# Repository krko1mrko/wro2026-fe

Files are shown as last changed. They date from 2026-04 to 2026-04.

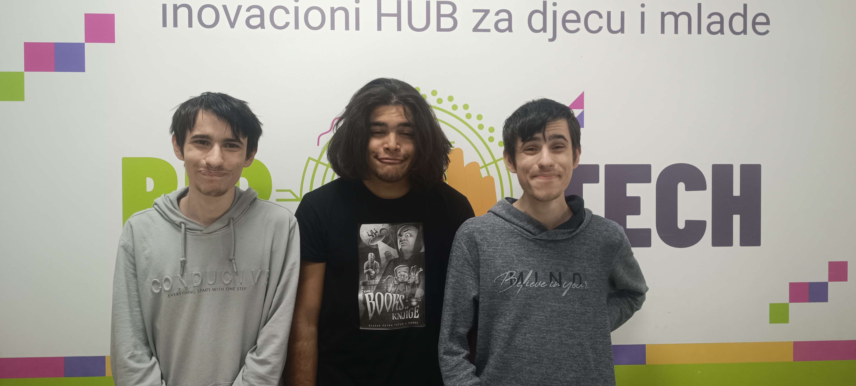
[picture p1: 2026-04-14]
t-photos/funny_image.jpg

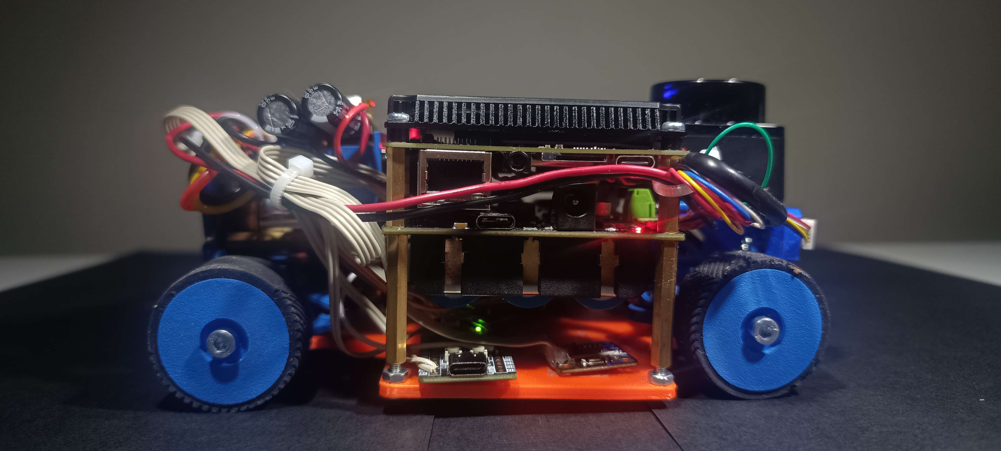
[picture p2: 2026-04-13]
v-photos/IMG_20260413_161818.jpg

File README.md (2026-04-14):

<br><h1 align=center> Team Ouroboros – WRO 2026 Future Engineers<br><br>

## Robot Overview

This repository contains the complete software system developed by Team Ouroboros for the WRO 2026 Future Engineers competition. The robot is a fully autonomous vehicle designed to complete both the Open Challenge and the Obstacle Challenge using a combination of advanced mechanical design and optimized software architecture.

The platform is based on a four-wheel drive and four-wheel steering configuration, allowing for improved maneuverability and traction. The software is designed to operate in real time, using multiple sensors and optimized algorithms for localization, perception, and decision-making.

---

## System Architecture

The system is divided into multiple modules, each responsible for a specific function. These modules interact to form a complete autonomous control pipeline.

### High-Level Data Flow

Sensor Data → Sensor Processing → Localization → Path Planning → Control → Actuation

---

## Software Modules

### 1. Sensor Interface Module

This module is responsible for acquiring and preprocessing data from all sensors used in the system.

Sensors include:
- LiDAR (STL-27L 360° DTOF) – environment mapping and obstacle detection  
- IMU (BNO055) – orientation and heading estimation  
- Camera (LattePanda 5MP UVC) – signal detection  
- Encoder (AS5600) – motor rotation and distance estimation  

The module ensures synchronized and structured data delivery to higher-level components.

---

### 2. Localization Module

The localization system determines the position and orientation of the robot within the map.

The main algorithm used is ICP (Iterative Closest Point), which aligns LiDAR scans with a pre-generated reference map. The odometry provides an initial estimate of the transformation to improve convergence speed.

To ensure real-time performance:
- A quad tree data structure is used for efficient spatial indexing  
- Approximate nearest neighbor search is implemented  
- OpenCL is used for GPU acceleration  

The output of this module is the robot’s pose (x, y, heading).

---

### 3. Path Planning Module

This module determines the optimal trajectory for the robot.

Two planning strategies are implemented:
- Open Challenge pathfinding  
- Obstacle avoidance pathfinding  

The planner uses the robot’s current position and environmental data to generate a path using Hybrid A* algorithm. It avoides obsticles while generating one of the shortest paths possible given the robot dynamics.

---

### 4. Obstacle Detection and Avoidance Module

This module processes LiDAR data and camera reading to detect dynamic obstacles and avoid them while following the signal rules.

Steps include:
- Detection of obstacles from point cloud data and camera readings
- Classification of detected objects
- Modification of trajectory to avoid collisions  

This module ensures safe navigation during the obstacle challenge.

---

### 5. Control Module

The control module converts planned trajectories into actuator commands. It uses a Stanley controller with a predictive element for mitigation of system response time.

Responsibilities include:
- Motor speed control
- Steering angle control
- Real-time corrections based on feedback  

This module communicates directly with the microcontroller for execution and operates on a separate thread for continious updating.

---

## Hardware and Software Integration

The software is tightly coupled with the robot’s electromechanical system. System parameters are updated in software to match the hardware.

### Main Components

- Main processor: Intel N150 (runs high-level algorithms)  
- Microcontroller: STM32 (handles real-time control)  
- Drive motor: BLDC motor with gearbox  
- Steering actuator: serial servo motor  

### Interaction

- The main processor processes sensor data and computes control commands  
- Commands are sent to the STM32 microcontroller  
- The STM32 controls motors and actuators  
- Feedback from sensors is continuously processed  

This separation ensures stable real-time performance.

---

## Build Instructions

### Dependencies

- Ubuntu operating system: (https://ubuntu.com/tutorials/install-ubuntu-desktop#1-overview)
- C++ compiler (g++) (https://gist.github.com/hugoledoux/2e91ed3efbfa8ca5da1ea27e522d2b34)
- OpenCL ICD:
    - OpenCL: https://github.com/KhronosGroup/OpenCL-Guide/blob/main/chapters/getting_started_linux.md
    - Driver: https://support.zivid.com/en/latest/camera/getting-started/software-installation/gpu/install-opencl-drivers-ubuntu.html
- OpenCV Library: (https://docs.opencv.org/3.4/d7/d9f/tutorial_linux_install.html)
- Arduino IDE  (https://support.arduino.cc/hc/en-us/articles/360019833020-Download-and-install-Arduino-IDE)
- STM32duino (https://github.com/stm32duino#welcome-to-the-stm32duino-open-source-community)
- SCServo Library (https://github.com/adityakamath/SCServo_Linux?tab=readme-ov-file#scservo_linux)
- Modified SimonK firmware for the ESC (Depending on your ESC choice, the firmware may vary) (https://github.com/sim-/tgy)

### Steps

1. Clone the repository and enter the directory:

```bash
git clone https://github.com/krko1mrko/wro2026-fe  
cd wro2026-fe/code
```

2. Build the project:

```bash
g++ *.cpp -fpermissive 'pkg-config --cflags --libs opencv4' -lOpenCL -O3 -o main
```

3. Ensure all dependencies are properly installed and linked.

---

### Microcontroller (STM32)

1. Connect the STM32 board via USB  
2. Open Arduino IDE or compatible environment  
3. Select the correct board and port  
4. Upload the firmware  

---

## Execution Loop

The system operates in a continuous loop:

1. Sensors acquire environmental data  
2. Data is processed and filtered  
3. Localization estimates robot pose  
4. Path planning determines next movement  
5. Control module generates commands  
6. STM32 executes motor and steering actions  

---

## Configuration

System parameters such as speed limits, control constants, and sensor calibration values
are defined within the source code and can be adjusted prior to compilation.

## Additional Notes

- The system minimizes external dependencies to improve portability  
- Performance is optimized through algorithm design and GPU acceleration  
- The modular structure allows easy debugging and future expansion  

---

## Repository Structure

/t-photos
/v-photos
/video
/CAD Files.zip
/wro2026-fe-ouroboros-docs
/README.md

---

## Conclusion

The presented system combines mechanical design and optimized software architecture to achieve reliable autonomous navigation. The modular design, efficient algorithms, and tight integration with hardware allow the robot to operate effectively within the constraints of the WRO 2026 Future Engineers competition.

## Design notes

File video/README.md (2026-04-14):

# Video Material

The following Youtube URL's are showing a 30 second robot video in both open and obstacle challenge.

- Open challenge: https://youtu.be/--TAmBv7YcM
- Obstacle challenge: https://youtu.be/LMDbXpmT5yE

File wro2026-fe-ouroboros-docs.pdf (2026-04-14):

# ROBOT DOCUMENTATION FOR WRO 2026 FUTURE ENGINEERS

## Team Ouroboros

## Authors: Blazo Barovic Lazar Milicevic Milos Milicevic

Introduction | 3
Abstract | 3
Mobility & Mechanical Design | 3
Chassis Design Choices | 3
Steering and Drive Mechanism Justification | 4
Torque/speed reasoning | 5
Mechanical Stability | 5
Power & Sensor Architecture | 5
Power System | 5
Processing Units | 6
Sensor System | 6
LiDAR | 6
IMU | 6
Camera | 6
Encoder | 6
Software Architecture & Obstacle Strategy | 7
Introduction | 7
Explanation of algorithms | 7
Localization Algorithm (ICP) | 8
Signal handling | 10
Signal Mapping | 10
Waypoint Generation | 10
Testing & Evaluation | 11
Mechanical Testing | 11
Localization Accuracy | 11
Algorithm Performance | 11
Revisions & Improvements | 11
Overall Revisions | 11
Tire Choice | 12
Design Process | 13
Conclusion | 16

## Introduction

In this documentation, we describe the thought process, implementation, and design challenges encountered during the WRO 2026 Future Engineers challenge. The focus of this document is not only to present the final system, but also to clearly explain the reasoning behind key design decisions and the trade-offs considered during development.

In addition, we present the working principles of the robot, including its mechanical design and the implementation of the algorithms used in the system.

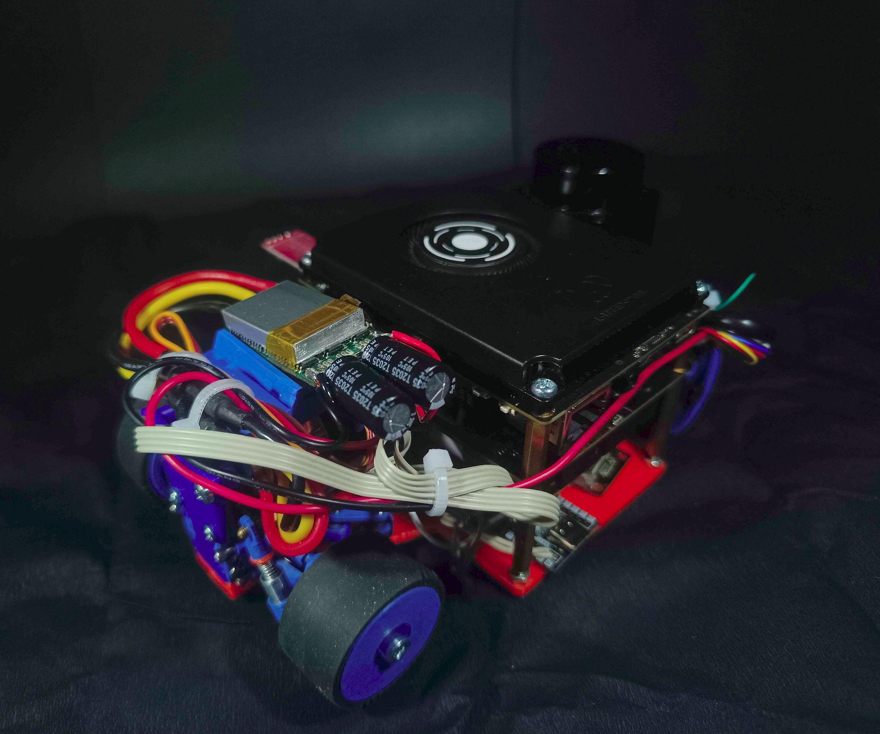
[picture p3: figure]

## Abstract

During the development of the robot for this year’s challenge, multiple design approaches were evaluated based on performance, complexity, and reliability. Due to these factors, the robot was designed as a four-wheel drive and four-wheel steering platform. This configuration was selected to improve traction, acceleration, and maneuverability, which are critical for navigating the competition environment.

The robot is equipped with passive suspension to ensure consistent contact of all four-wheels with the surface during operation. This improves stability and helps maintain reliable traction and sensor performance.

The robot utilizes multiple sensors to accurately determine its position and heading relative to the map. These sensors include a two-dimensional planar LiDAR sensor, a 9-DOF IMU, magnetic absolute position encoder and a 5-megapixel USB camera. Each sensor was selected for its specific advantages, and together they provide complementary data for robust perception and localization. The sensor data is processed and fused within the system.

For handling autonomous actions, the robot utilizes multiple algorithms corresponding to the challenges in this year’s competition. We use three different algorithms:

- Pathfinding algorithm for the open challenge
- Pathfinding algorithm for the obstacle avoidance challenge
- All-purpose localization algorithm

During development, we evaluated the accuracy and execution speed of individual subsystems, as well as the system as a whole, in order to ensure reliable real-time performance within hardware constraints.

## Mobility & Mechanical Design

Chassis Design Choices
During the development, the team has looked into multiple options for the chassis design based on the optimizations of the robot’s speed, acceleration and turning radius. The decision was made to keep the size of the robot as small as possible. This reduces our weight and increases our clearance from signals and walls during the locomotion of the robot. The robot is made using FDM (Fused Deposition Modeling) 3D printing technology. The plastic that is primarily used is PLA, but a select number of parts are made with ABS and TPU plastics. Other than plastic components, we use common mechanical parts such as bearings, screws, nuts, and heat inserts. We are also using off-the-shelf components such as: small form factor CVDs (Constant Velocity Drive) and open differentials, as well as metal gears. Some of the parts were manufactured out of aluminum using a lathe.
Robot mounting is primarily done by heat inserts and screws. Most of our screws mounting is done using M2 screws. Certain systems that are semi-decoupled from the robot base are attached with hinge joints and ball joints. These joints are made out of plastic using a 3D printer with a 0.25mm nozzle so that the feature size is as small as possible. This was a necessity because of the relatively small size of our robot (Figure 1.1).

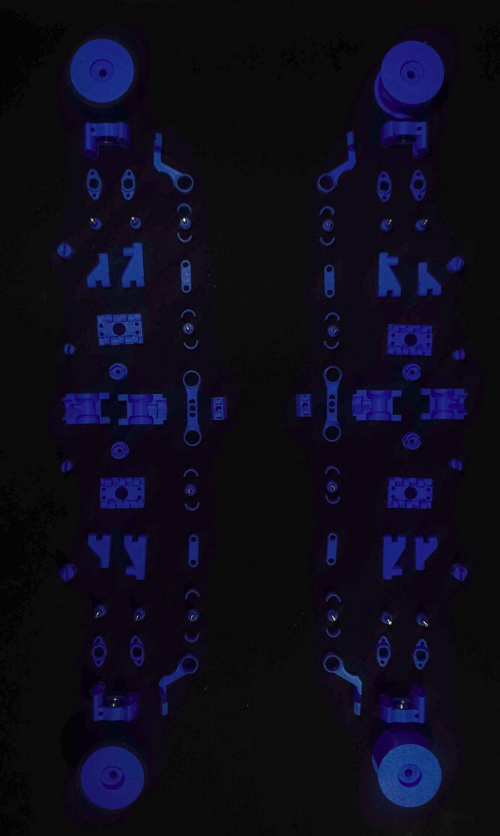
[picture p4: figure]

Steering and Drive Mechanism Justification
For the optimization of the robot’s speed and acceleration, we’ve decided to go with a four-wheel drive mechanism. This allows us to achieve higher acceleration by applying torque to all four-wheels, which increases our traction. Other factors that influence maximum speed and acceleration are choice of motor, gear ratio, tire diameter and material, excluding any aerodynamic effects.
Due to the additional challenge of parallel parking in the obstacle challenge, it was important to minimize turning radius. This also greatly benefits our ability to avoid signals and other collisions, significantly increasing our maneuverability. This is done by implementing a four-wheel steering mechanism. This considerably decreases our turning radius compared to two wheel steering. However, due to the limitation of using a single steering motor, we are incapable of dynamically adjusting the steering ratio of the front and back wheels. This forces us to optimize for either low speed or high speed maneuvers. Due to the nature of the challenge, this makes it so that optimizing for low speed maneuvers is more beneficial, therefore the steering ratio between the front and back axle is 1:1. The steering is inspired by Ackermann steering geometry.

The drive utilizes two differentials, one on the front axle and one on the rear axle, enabling four-wheel drive. Due to the expected symmetrical load distribution between the front and rear axles, a third (central) differential is not required.

Instead, both axles are directly coupled, which simplifies the drivetrain and reduces overall backlash in the system.

Torque/speed reasoning
Torque and speed heavily depend on motor choice, but some other factors are gear ratio and wheel diameter, as well as the mechanical transmission efficiency. The motor we chose to go with is a 2830 1000-KV motor. This provides us with high speed and low torque. Torque directly from the motor would be insufficient, thus a gearbox is used. The gearbox ratio is 10:1, whilst the final drive ratio is 2:1, giving us a total ratio of 20:1. The wheel diameter is 34mm. This provides us with a balance between our torque and speed, allowing quick acceleration with a high maximum speed. The motor is more powerful than the use case requires, therefore it’s limited to a max power and speed more in line with our needs.

Mechanical Stability
Some systems don’t require high stability, whilst for others it's crucial for it to be stable with low backlash and higher rigidity. Based on these factors, we have designed our system for the needs of our robot, thus, parts such as the steering knuckle, wishbones, hinge joints, the drive mechanism and the steering system are made as rigidly as possible within the size constraint, whereas parts such as electronics mounting, the backplate are made with limited strength to save space as these parts do not require it.

## Power & Sensor Architecture

The robot’s electrical and sensing architecture were designed to ensure reliable operation, efficient power distribution, and accurate data acquisition from all sensors.

Power System

The robot is powered using a 3S1P (3 Series, 1 Parallel) lithium-ion battery configuration. The battery was selected based on its energy density, discharge rate, and size constraints.

Power is distributed to different subsystems using Smart UPS Expansion Board for LattePanda IOTA (18650 Battery). Different voltage levels are required for various components:

- BLDC Motor: 12V, direct from battery
- Servo Motor: 12V, direct from battery

- Microcontroller STM32: 5V, from linear voltage regulator
- LiDAR: 5V, from USB
- BNO055 IMU: 3.3V, LattePanda IOTA breakout
- LattePanda 5MP UVC Camera: 5V, from breakout
- AS5600 Encoder: 3.3V, from STM32

Voltage regulation is handled using Smart UPS expansion board, ensuring stable operation and protecting sensitive electronics, as well as handling battery management functionality, such as overcharge protection, overdischarge protection and overcurrent protection.

Processing Units

The robot utilizes multiple processing units to handle different tasks:

- Main processor: Intel N150
- Microcontroller: STM32

The main processor is responsible for high-level tasks such as:

- Sensor fusion
- Localization
- Path planning
- Machine vision

The microcontroller is responsible for:

- Low-level motor control
- Servo control
- Real-time actuation

Sensor System

The robot uses a combination of sensors to achieve robust perception:

- LiDAR: Used for distance measurement and environment mapping
- IMU: Used for orientation and motion estimation
- Camera: Used for signal detection
- Encoder: Used to provide an approximate position estimate.

LiDAR

Model: STL-27L 360° DTOF LIDAR Sensor (UART, 25m)

- Range: 25m

The LiDAR provides point cloud data used for localization and obstacle detection, including environment mapping.

IMU

Model: BNO055

- Degrees of freedom: 9
- Data used: heading angle

The IMU provides high-frequency motion data used as an initial estimate in the localization algorithm.

Camera

Model: LattePanda 5MP UVC
Camera
- Resolution: 5 MP

The camera is used for signal detection.

Encoder

Model: AS5600

The AS5600 is a high-precision, 12-bit contactless magnetic rotary position sensor that provides absolute angle measurement over a 360-degree range. As we have attached it to the backside of the motor, where it measures rotation that can then be converted into distance traveled. The encoder was necessary because the accuracy of the robot was not ideal, therefore we needed to add a feedback loop.

### Actuators

For the actuation and movement of the robot, only two actuators are used. One being the steering servo, whilst the other one is the drive motor.
The steering servo is a serial servo supplied with 12V. The servo has three wires. Such that they are: 12V, GND and data. The servo serial communication is a half duplex UART (Universal Asynchronous Receive Transmit) connection running at a baud rate of 1M. Its commands are sent by the STM32 microcontroller.
The drive motor is a 1000KV 11 pole BLDC (Brushless DC) motor. This kind of motor relies on electronic communication which is handled by an ESC (Electronic Speed Controller). For the purposes of this vehicle it was needed for the speed controller to support bidirectional commutation. This is not a default setting in many affordable ESC’s used for such drone motors. For this reason, it was needed to flash a custom firmware that would enable such a feature. The firmware of choice was the popular SimonK. It’s tailor made for such cheap ATmega based ESC’s. The ESC is controlled by a PWM signal whose pulse width ranges from 1060-2060us. This PWM signal is generated by the STM32 microcontroller. It’s supplied with 12V, same as the servo.

## Software Architecture & Obstacle Strategy

Introduction
During the development of the robot software, it was the team’s goal to minimize external dependencies such as libraries, executables, or SDKs. For this reason the only dependencies used are OpenCL, OpenCV and Arduino libraries (SCServo, Servo).
The system is built on top of the open source operating system Ubuntu. Due to the hardware limitations in such a small form factor it was important to choose a highly performant programming language that allowed for low access and was compatible with the aforementioned libraries. The choice boiled down to C or C++, and C++ was chosen due to previous experience with the language.

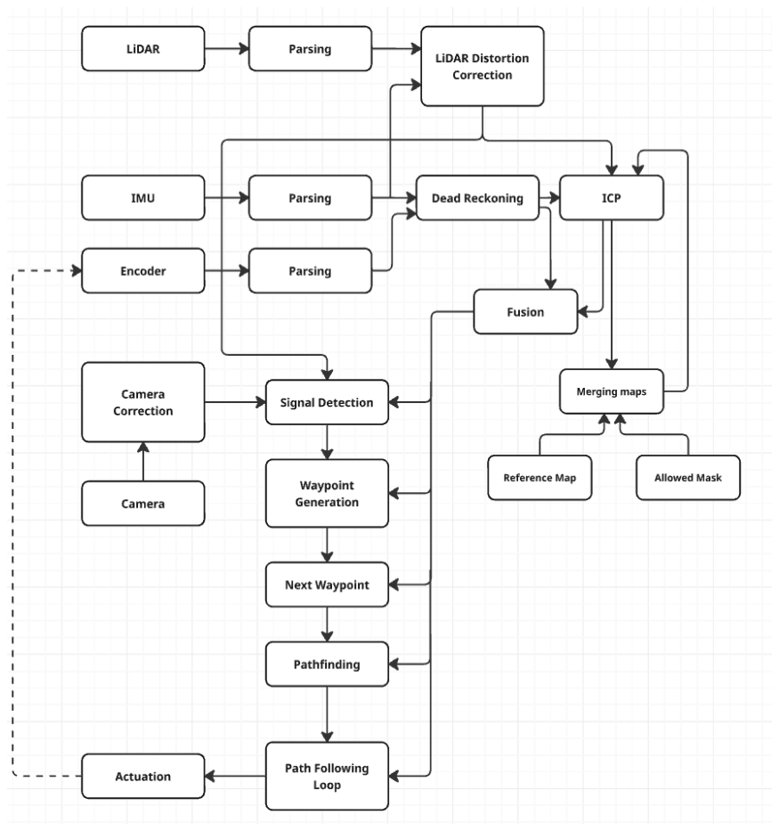
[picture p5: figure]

Explanation of algorithms

The main problem in robotics of this type boils down to 2 simple questions:
- Where is the robot?
- Where to go next?
To answer these questions many methods are used in the industry and research. The question of Where is the robot? is in essence a localization problem. Many robots on this scale use what is called dead reckoning using odometry. This is the process by which the robot's position is determined based on the previous robot position and a calculated or measured change in position from wheel encoders. But due to its iterative nature, any and all measurement errors will be added up, and they will tend to increase the error between our predicted position and real position. This is called drift. Previously on the WRO RoboMission 2025 our team developed such a system, but due to the previously mentioned drift as well as the significantly bigger track length of the WRO Future Engineers 2026 map that would amplify the total error further we decided to research other alternatives.
One method that is often mentioned in the literature is use of a local or global positioning system such as GPS or GNSS. But due to rule 11.6. - “A vehicle must be autonomous and finish the “missions” by itself. Any radio communication, remote control, and wired control systems are not allowed while the vehicle is running. Teams in violation of this rule will be disqualified.” that forbids external communication such methods are not useful for our use case. Another method is SLAM
(Simultaneous Localization and Mapping) using a combination of sensors. These sensors most often include LIDARs and IMUs. The SLAM system uses the LIDAR point cloud reading and matches it to a previously constructed map. This is most often done with the ICP (Iterative Closest Point) algorithm. The IMU provides an initial guess of the current transformation of the points. This guess is then used for the first iteration of ICP. This boosts convergence speeds and reduces possible errors, as long as the IMU readings are properly filtered. If the new readings are added to the map this will cause drift over time as small errors add up. This is often solved by a system often referred to as loop closure, but due to the algorithm’s complexity and relatively small and known environment for this challenge we decided it would be better if we performed ICP using a pre-generated map. This map would be appended with the dynamic elements of the challenge (signals or randomized walls).
Prebuilt solutions for such a SLAM system exist within software packages such as ROS 2, but due to the previously stated self-imposed limitations on the software dependencies, we decided to implement our own even if its performance is worse than existing solutions.

Localization Algorithm (ICP)

The ICP algorithm is used to align LiDAR scans with a pre-generated map. The algorithm iteratively minimizes the distance between corresponding points. For each point, in a LiDAR scan, it finds the closest point from the reference map forming a point pair. This is done with a nearest neighbor search algorithm. The exact implementation is described later. After forming the pairs, a least squares solution for the transform (including translation and rotation) is solved. This transform is then applied to the original scan and the process is repeated until the error converges or a maximum number of cycles is exceeded.

The nearest neighbor search (from now on NNS) is performed for all the points in the scan (around 2160) across all iterations (max. 100, average 20), in searches across a reference map containing approximately 10000 points. If a simple NNS algorithm that iterates for each point in the scan across the whole reference map to find the nearest point it quickly becomes computationally expensive. This approach would be unable to perform ICP in the 100ms between each LiDAR scan. A different implementation had to be used.

A different data structure for the reference map was the most effective solution. A spatially indexed data structure was chosen due to the relatively static nature of the reference map. Two options were considered:

1. K-D Tree
2. Quad tree

The main deciding factor was the simplicity of tree generation. Quad trees were easier to generate.

To further save on computation an approximate NNS algorithm was used. This involved only navigating down the quad tree once per point without backtracking. To accommodate this change, the reference map is rotated by 45° to decrease the chances of a line of points, aligning with the quad border.

This was still underperforming, so the next best optimization was multithreading. To take advantage of the onboard GPU for general purpose parallelized computation, an OpenCL kernel was used. As per recommendations in the OpenCL™ Developer Guide for Intel® Processor Graphics

1
. The biggest
performance increase comes from proper and efficient memory usage. To aid in this we decided to decrease the overall size of the quad tree data structure. Each quad is only 8 bytes big such that it contains an id (4 bytes) that describes the exact position of the quad and its size. The remaining 4 bytes are used for storing the children offset in the array and their number.
The whole data structure is stored in an array of quads with the first element being the quad tree root. In addition to this the position and size of the root elements are passed in as 3 constant values (x, y, width).
To further optimize the runtime of the OpenCL kernel we only pass in the scan points once, and on subsequent iterations of the ICP we only update the transform that is applied to these points. It might seem counterintuitive to perform the point transformation twice, once on the CPU and once on the GPU, but the memory bandwidth reduction greatly outweighs any computational increase.
After implementing all these optimizations the execution of ICP for a single scan goes from >1s for the naive NNS algorithm to below 50ms. The algorithm only uses one CPU thread and therefore allows for additional processes such as communication, control loops and related processes.

1https://www.intel.com/content/www/us/en/content-details/774834/opencl-developer-guide-for-intel-processor-graphics.ht ml (https://www.intel.com/content/www/us/en/content-details/774834/opencl-developer-guide-for-intel-processor-graphics.html)

### Creating & Updating Reference Map

The reference map used in the ICP starts with already predefined points such as the outer walls and in case of obstacle challenge the parking spot. This reference map is dynamic, points are added to it as the robot explores its environment. The points that are added are first put through a mask. This mask blocks out the addition of any points on the drive surface, excluding signal positions. We have a secondary check before adding any points. These points must temporally agree on their positions in multiple previous readings before being added.

### LiDAR Distortion Correction

To improve the accuracy and stability of the ICP algorithm, it is necessary to correct the LiDAR data in its uncorrected form. The points from LiDAR are distorted due to the robot rotating during the scan. We correct for this rotation with historical data from the IMU.

### Dead Reckoning

Dead Reckoning is the process in which we calculate the changing position and rotation based on inertial measurements of the robot. These measurements are heading from the IMU and motor encoder.

### Fusion

We are using the simplest sensor fusion implementation in case ICP fails to converge to a low cost value. We fall back on dead reckoning for position, until the ICP converges again.

### Pathfinding Algorithm

The pathfinding algorithm is an algorithm that takes in the environment map, current position, system parameters, target position information and returns us a valid path to our end goal. The algorithm takes into account both position and rotation of the robot as well as the target position. The environment map is a point cloud. It consists of points that represent the walls and signals as well as points that represent virtual walls constraining our movement to the desired path. A valid path is any path that the robot can execute without colliding with signals or walls and that gets it to the target position.
To achieve this we are using the Hybrid A* algorithm tailored to a Reeds-Shepp vehicle. This vehicle is described with a minimal turning radius. It can only perform one of six actions: move forwards and backwards, steer left or right during those motions as shown on the figure (Figure 1.2).

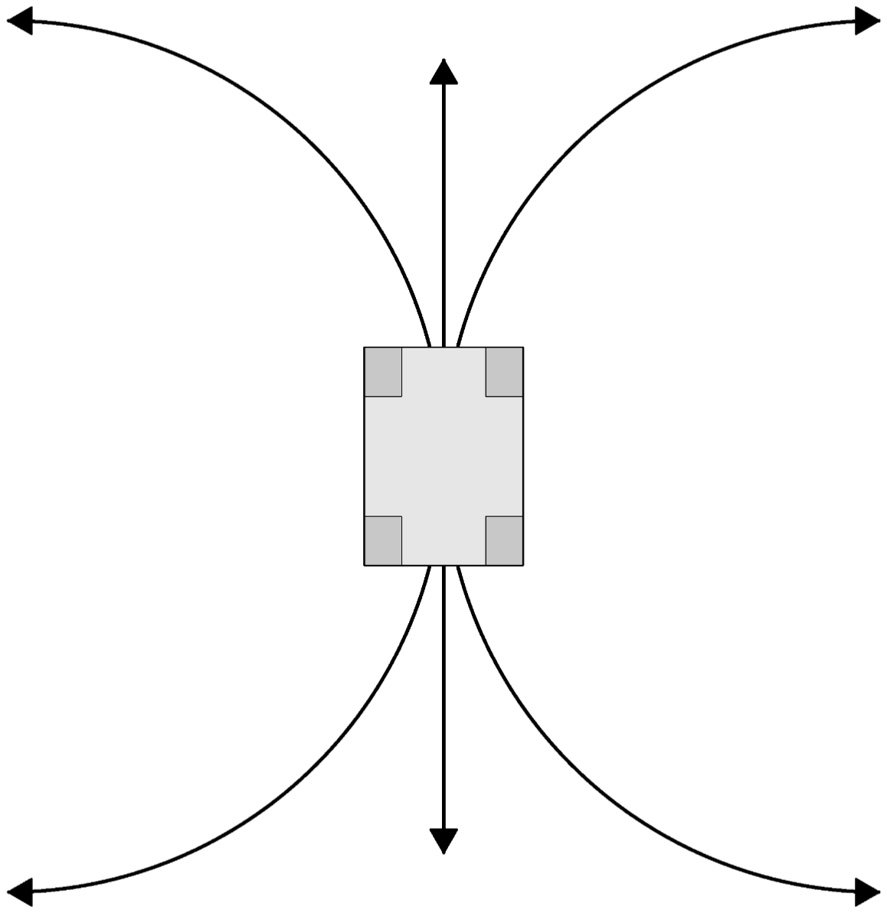
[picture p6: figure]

Figure 1.2.

Hybrid A* algorithm starts with a single node which is described by the vehicle's initial position and rotation. As this the only node, it is used for generation of six additional nodes. These new nodes correspond to the positions and rotations of the robot when traveling along each of the six possible movements for a distance equaling the step size. Each of these nodes check if the robot would collide with the environment in that position, this is a simple radial distance check. If it does collide, the node is deleted. For the remaining nodes, a cost is calculated. This cost is equal to the length of the shortest Reeds-Shepp path. These new nodes are inserted into an array of possible future positions. For the next iteration, the starting node is picked from this array, such that it is the element with the least cost. This process is repeated until one of three conditions are met:

1. There are no more possible nodes, in which case the
algorithm would return no
path.
2. If the computation time is exceeded, it returns no path.
3. If a valid Reeds-Shepp path is found from the last
explored node to the target position, such that the robot does not collide with the
environment whilst it follows that path. Then we return the Hybrid A* path with
appended Reeds-Shepp
path.

To determine if the Reeds-Shepp path produces a collision with the environment, we use an approach similar to ray marching where we iteratively go along the path for a minimum distance from the environment and on each spot we check if that minimum distance is less than a collision threshold. If for any of these points that condition is true, the path results in a collision.

### Starting Position

To find the initial position of the robot on the map, we used the previously described ICP algorithm and run a single iteration from each possible starting position and rotation and pick one with the lowest cost. Due to the symmetry of the map’s external walls, only twelve unique starting positions for the open challenge exist and only two for the obstacle challenge.

Signal handling

To perform signal handling we have to know three things: the drive direction of the vehicle during a round, the color of the signals and their positions. We have to know all three of these to be able to determine the positions of waypoints in global scope.

Signal Mapping

To determine the position and color of the signals, we use data from the camera, LiDAR and the position returned by the ICP algorithm. The first step is to calibrate the camera. This is done using OpenCV’s implementation of camera calibration. Next, we crop the image to the ROI (Region Of Interest) such that we exclude the ground and the area above the walls. We convert the RGB (Red, Green, Blue) to HSV (Hue, Saturation, Value). First we create the mask by checking all of the pixel values that match a value range of a color. In the mask, we find contours, iterate over them and delete any that are too small.

We redraw the image from the remaining contours.
We match the FOV of the camera to a region of the LiDAR’s FOV. Afterward, we find the average distance and angle from the LiDAR to a detected signal. This distance and angle are converted to global coordinates. We store these positions in an array. If four separate calculations agree that the signal is found close to a possible position, we will add a signal to that position. We separately check for green and red.

Waypoint Generation

Waypoints are used in our
pathfinding as target positions. These waypoints are crucial for our signal handling as they determine the factoring path chosen by the robot. When the robot is moving in a CCW direction and detects a green signal, it generates a waypoint that is located inwards a certain distance away from the signal and if it sees a red signal, it
generates a point outwards. This is reversed if the direction is reversed. The signals also generate a waypoint if the signal is located close to the corner segment, it also generates a waypoint that is located on the middle of its straight segment. The signal has the same direction as the drive direction. To aid in the single detection, we have four fixed waypoints one on each corner segment rotated towards the next straight segment. The robot follows these points in an order of the drive direction, i.e. CW or CCW.

### Path Following

If the path is followed strictly based on the Reeds-Shepp path, a lot of jitter can be observed. For this reason, it was needed to perform path smoothing and correct for any deviation from the path in real time. To do this, we implemented a Stanley controller. This controller looks at the closest point on the path and the current state of the robot to determine the needed steering of the vehicle to get back onto the path.
This implementation had significant oscillations due to the response delay of the system, mainly the limited rate of change of the steering servo. To fix this, we introduced a predictive element that predicts the future position and rotation of the robot and uses it to calculate the command for the servo. The prediction window is tuned such that by the time we reach the predicted point in time, servo has moved to the position
commanded to it at the time of making the prediction.
In addition to this, if we are nearing the end of the planned path, we command the drive motor to decelerate.

## Testing & Evaluation

During development, the system was tested to evaluate performance, accuracy, and reliability.

Mechanical Testing

- Minimum turning radius: 330mm
- Maximum speed: 0.7

m
s
- Speed used: 0.5

m
s
- Acceleration: 0.25

m
s

2

Algorithm Performance

- Average computation time for the ICP algorithm: 5-90ms
- Average computation time for the pathfinding algorithm: 0-20ms

## Revisions & Improvements

Overall Revisions

During development, we had two major revisions: the first was purely conceptual design made fully parametric and fully adjustable for the sake of validation out the suspension and steering geometry.

This design was large, bulky and had fundamental flaws for the design. The good part about the initial design was its parametric nature. That allowed us to quickly adapt it after the initial time invested into making it parametric. This revision was primarily used before we committed to any choice of hardware, such as bearings, tires, CVD’s, differentials, gearbox, motor, etc.

The next major change was an overall reduction of size of all parts. Before any big changes, we aimed to evaluate the hardware we could use. We had a vast selection of parts to choose from on the bearing front, as well as on the drive train or drive base parts such as: CVD’s, shafts and differentials.

Tire Choice

But our biggest problem at the time was the material for tires. We were unable to source two part silicone, thus we needed to find a more readily available solution. After evaluation our choices, we had two options:

1. Caulk silicone
2. Silicone bike grips

From our previous experiences, we knew that we could manufacture tires out of caulk silicone. These tires would have pretty good performance, but we still wanted to evaluate the other options we did not try in the past that, after some research, we thought the second option of silicone grips could have better or equal performance than caulk silicone.

However, it depends on the material used and the geometry of the grips. We decided our best course of action was to check in local bicycle shops their selections of handle grips. We found what we were searching for, and evaluated that it had slightly better traction and was significantly sturdier than a solution made with caulk silicone.

Because of the fixed size of the inner diameter of the silicone grips, that was the approximate size we had to go with for our rims. This size could be slightly bigger as the silicone is stretchable. At the end, we decided to have a 26mm outer diameter of our rims whilst the grips had an inner diameter of 21mm. This ensures that the grips will not slip on the rim even with no patterns on the surface of the rim. The inside diameter of the rim is 24.5mm. From this choice, the scale of our steering knuckle and all the connected mechanisms were derived.

In this revision, the scale of the entire mechanism was reduced by a factor of two. Most of the hardware, i.e. bearings and joint sizes were finalised and a basic untuned steering geometry was implemented. The third and final revision mostly dealt with tuning: steering, gear meshing, suspension mechanisms, as well as tolerances for printed 3D-printed parts.

The first implemented steering was simplified Ackermann steering geometry. Whilst the subsequent revisions dealt with adapting such geometry to work with suspension and within our size constraints.

The following figures show our steering geometry in different development stages.

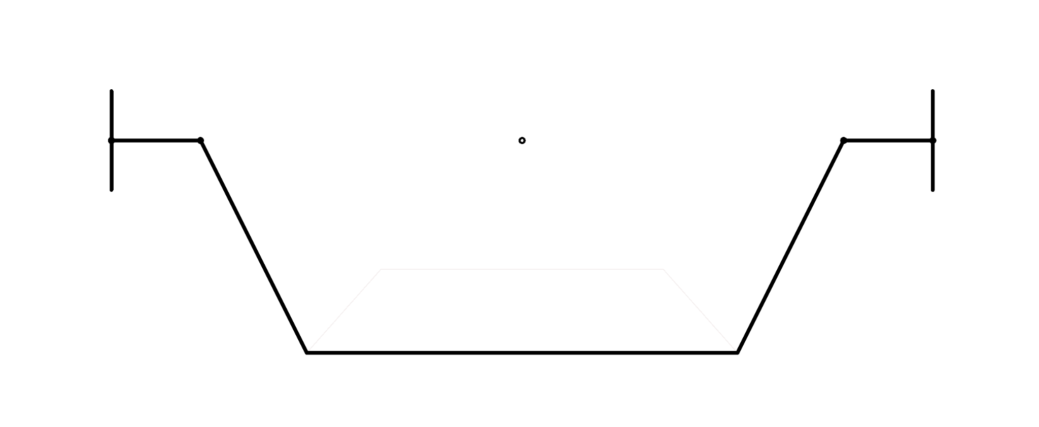
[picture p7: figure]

Figure 1.

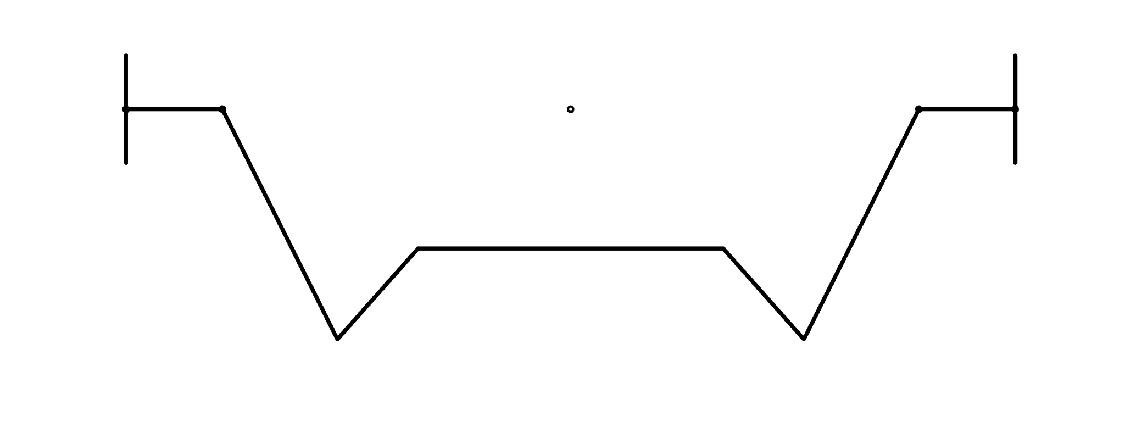
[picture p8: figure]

Figure 2.

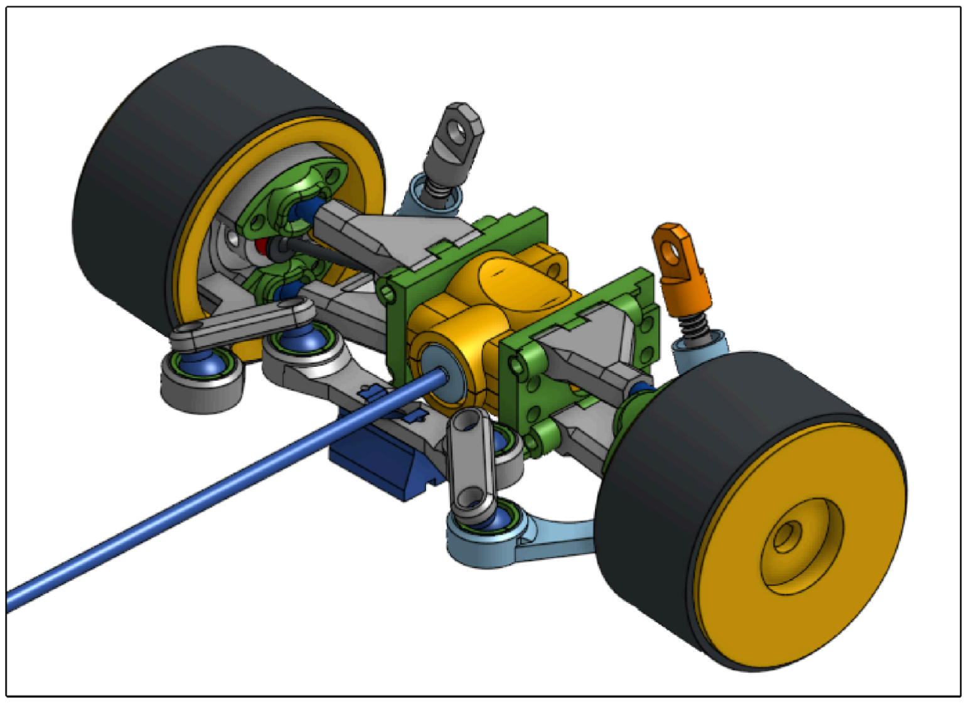
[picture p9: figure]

Figure 3.

Design Process

First version of the steering knuckle. This version was simplistic and meant as a proof of concept. It contained minimal features and did not satisfy our criteria, it was difficult to implement and hard to alter the CAD design (Figure 4.).

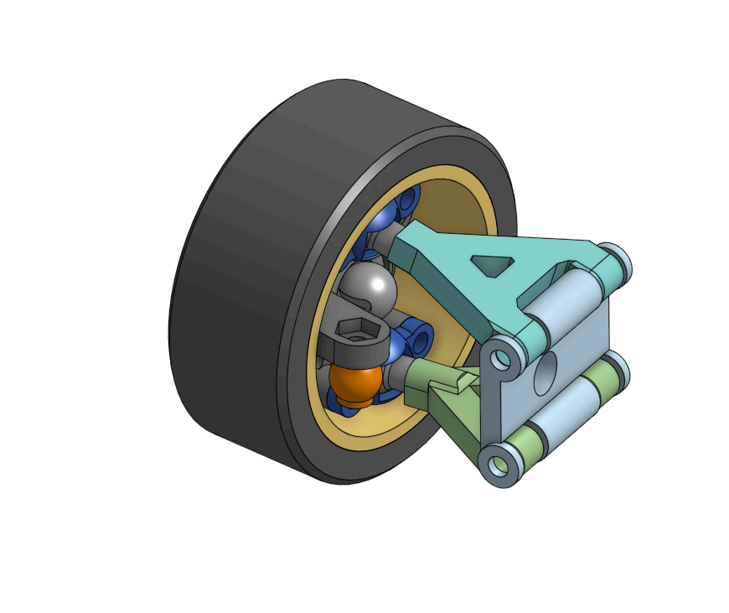
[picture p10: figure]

Figure 4.

Rework of the steering knuckle. Included caster angle and KPI in the initial base design. Did a fully parametric design for fast revisions. Finalized the design of the ball joints, connecting the steering knuckle to the wishbones (Figure 5.).

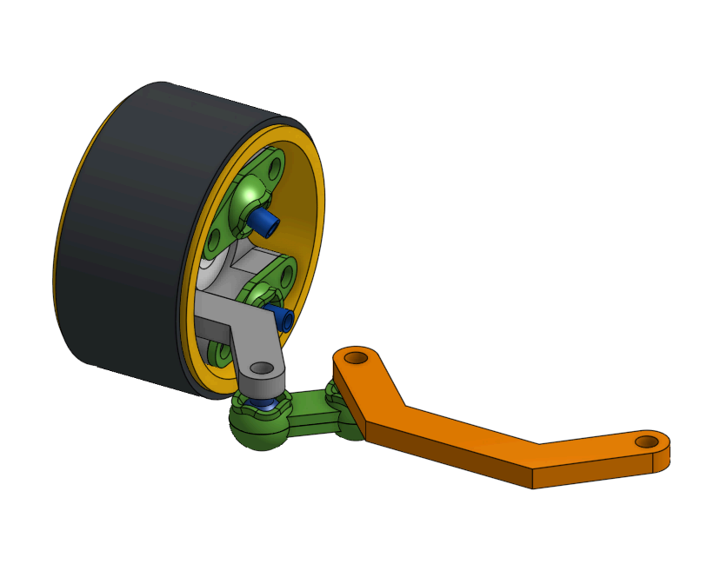
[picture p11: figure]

Figure 5.

Changed designed parameters, finalized size and determined tolerances used in printing of joints. Determined the usefulness of dry lubricants such as graphite, which did improve the performance of these joints (Figure 6.).

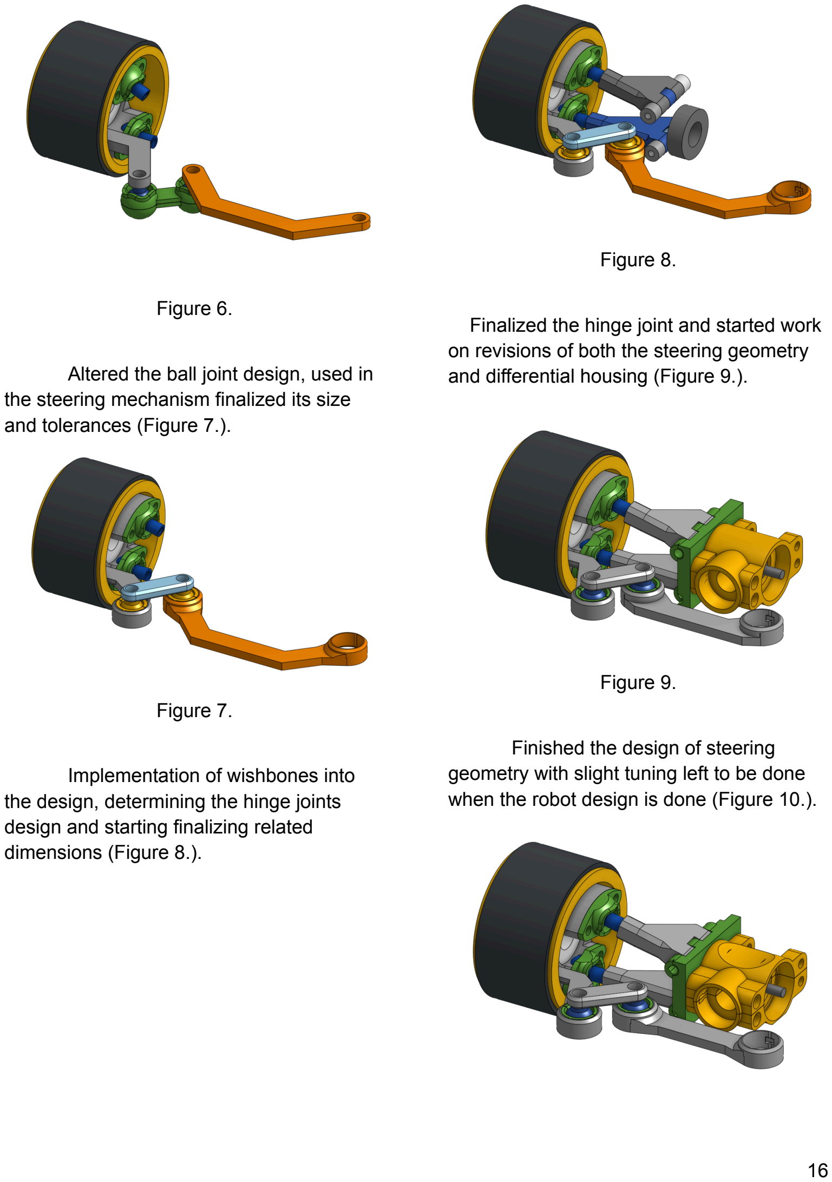
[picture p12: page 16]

Figure 6.

Altered the ball joint design, used in the steering mechanism finalized its size and tolerances (Figure 7.).

Figure 7.

Implementation of wishbones into the design, determining the hinge joints design and starting finalizing related dimensions (Figure 8.).

Figure 8.

Finalized the hinge joint and started work on revisions of both the steering geometry and differential housing (Figure 9.).

Figure 9.

Finished the design of steering geometry with slight tuning left to be done when the robot design is done (Figure 10.).

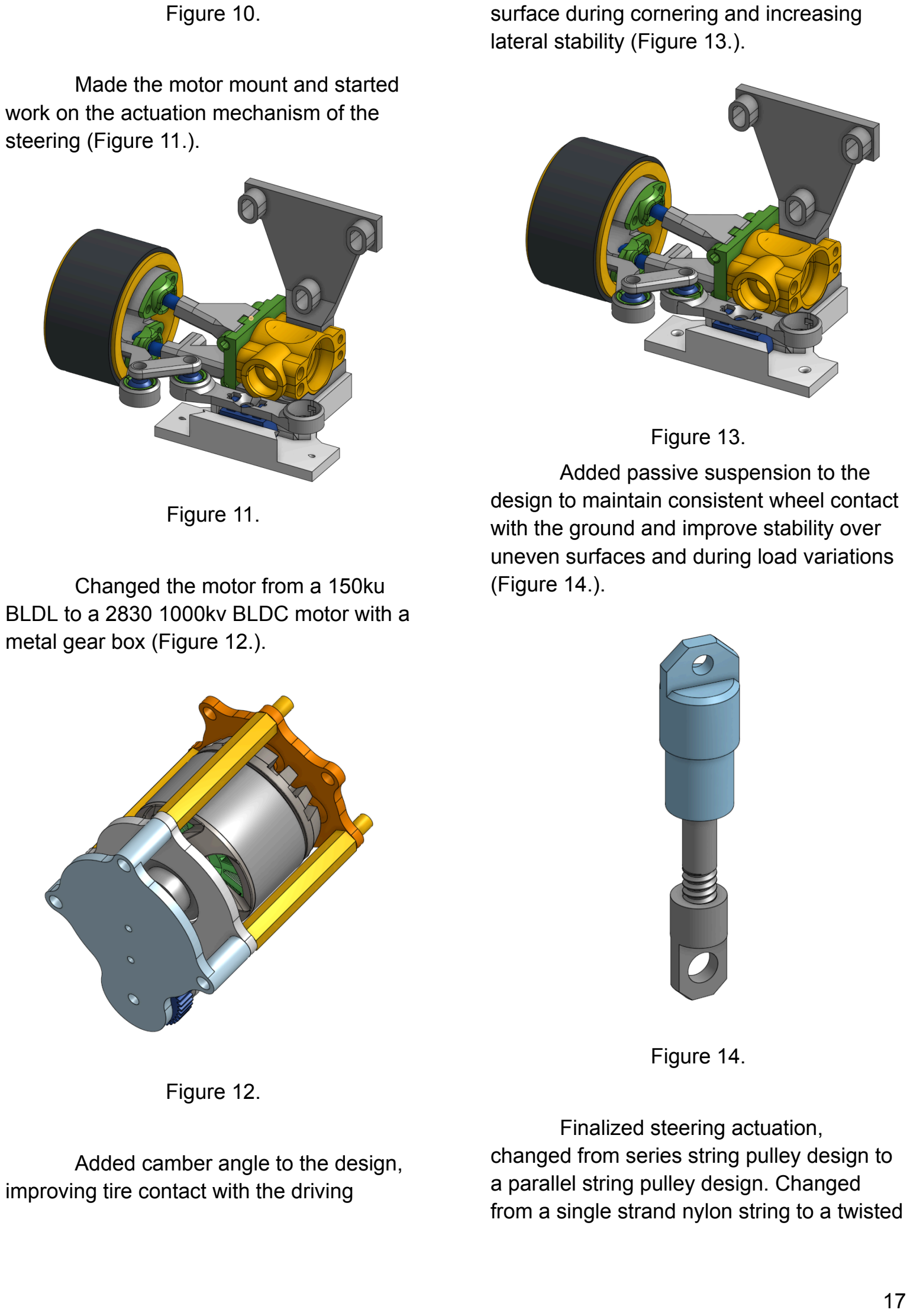
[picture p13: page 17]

Figure 10.

Made the motor mount and started work on the actuation mechanism of the steering (Figure 11.).

Figure 11.

Changed the motor from a 150ku BLDL to a 2830 1000kv BLDC motor with a metal gear box (Figure 12.).

Figure 12.

Added camber angle to the design, improving tire contact with the driving surface during cornering and increasing lateral stability (Figure 13.).

Figure 13.
Added passive suspension to the design to maintain consistent wheel contact with the ground and improve stability over uneven surfaces and during load variations (Figure 14.).

Figure 14.

Finalized steering actuation, changed from series string pulley design to a parallel string pulley design. Changed from a single strand nylon string to a twisted fishing line made to not stretch or deform (Figure 15. & 16.).

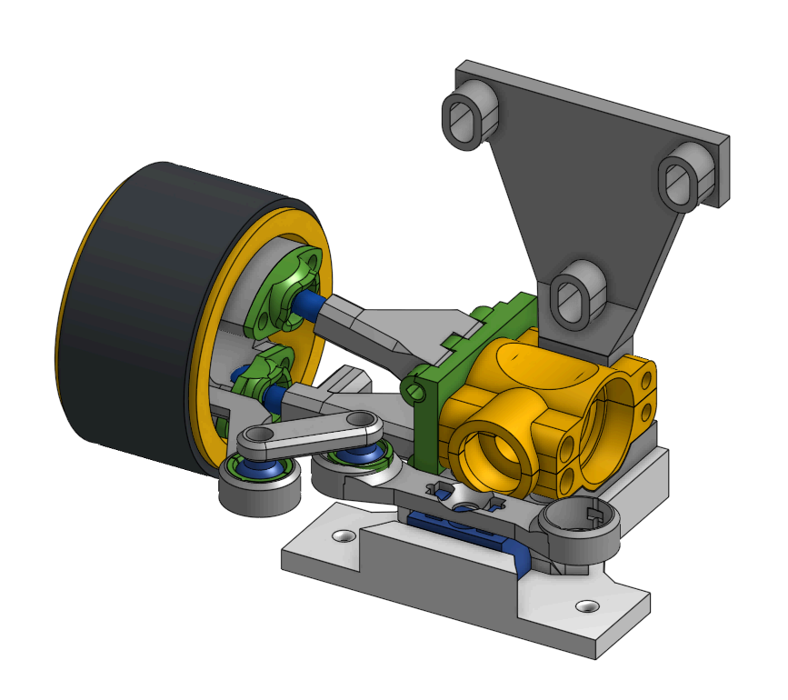
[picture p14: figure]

Figure 15.

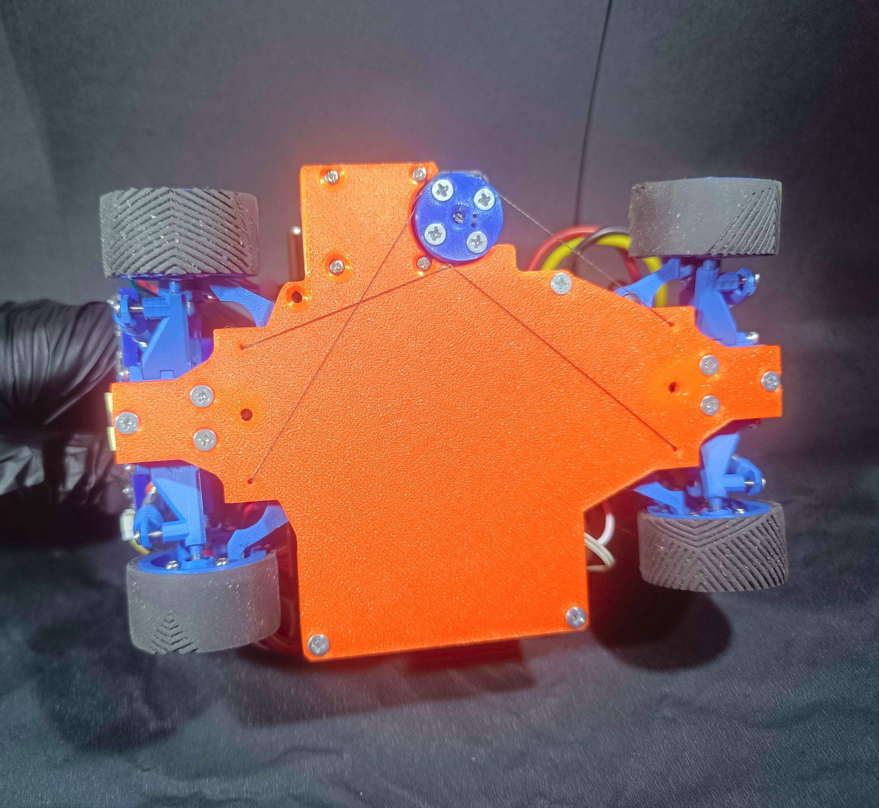
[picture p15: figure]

Figure 16.

The back board on which all the components are connected, changed tolerances and string channel sizes as well as added alignment holes used when tightening the steering actuation (Figure 17.).

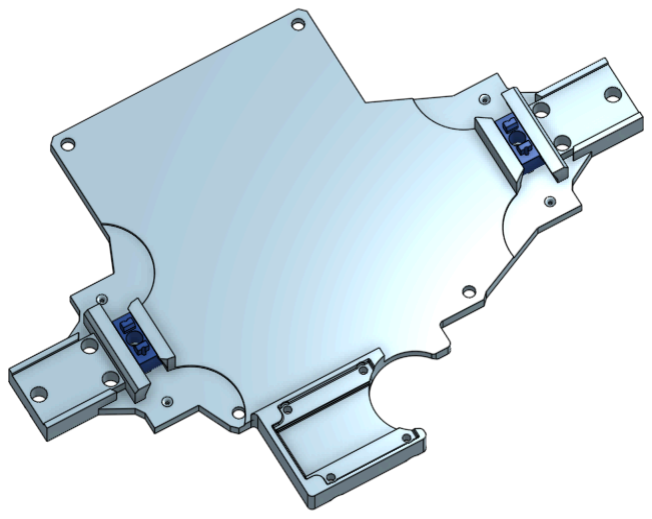
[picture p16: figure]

Figure 17.

## Conclusion

The developed robot represents a carefully balanced integration of mechanical design, sensor architecture, and software systems, with a strong emphasis on reliability, efficiency, and real-time performance.

Throughout the development process, each subsystem was iteratively refined and evaluated to ensure that it meets the constraints and challenges defined by the WRO 2026 Future Engineers competition.

The combination of a four-wheel drive and four-wheel steering platform provides high maneuverability and precise control, which is essential for navigating complex environments. The use of a LiDAR-based localization system, supported by IMU data and optimized through a custom implementation of the ICP algorithm, enables accurate and stable position estimation without reliance on external infrastructure.

In addition, the integration of path planning and obstacle handling algorithms allows the robot to adapt to both static and dynamic elements of the environment, ensuring safe and efficient navigation. Special attention was given to computational performance, resulting in a system capable of operating within strict real-time constraints.

Although further improvements can be made in certain areas, the current implementation demonstrates a robust and optimized solution. Overall, the system reflects a comprehensive engineering approach, combining theoretical understanding with practical design decisions to successfully address the requirements of the competition.

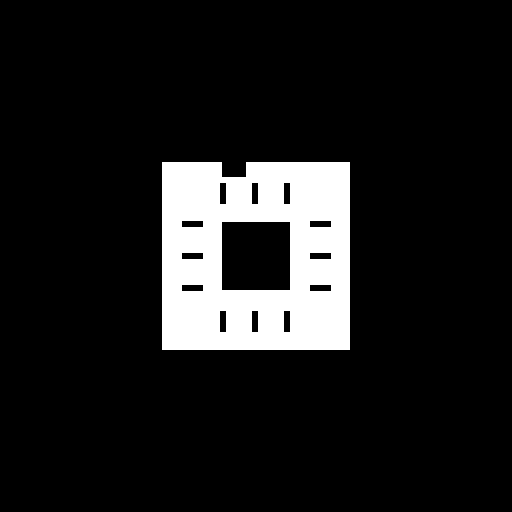
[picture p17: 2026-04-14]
code/obsticle_challenge_mask.bmp

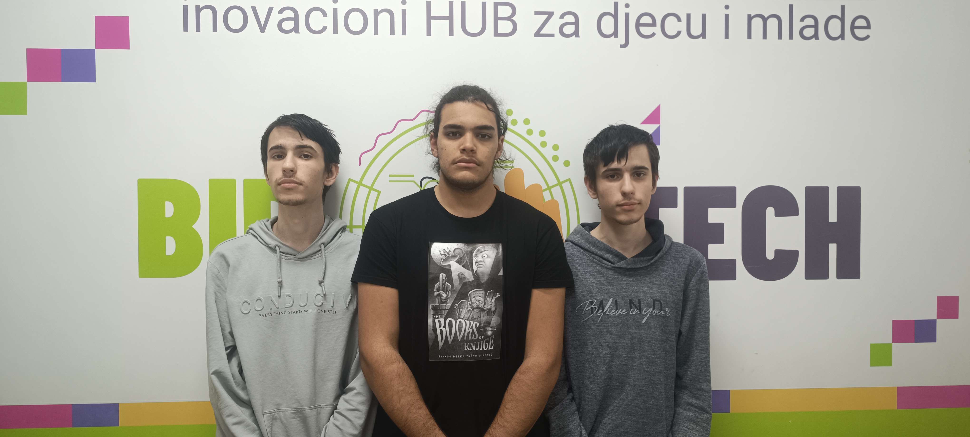
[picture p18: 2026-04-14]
t-photos/serious_image.jpg

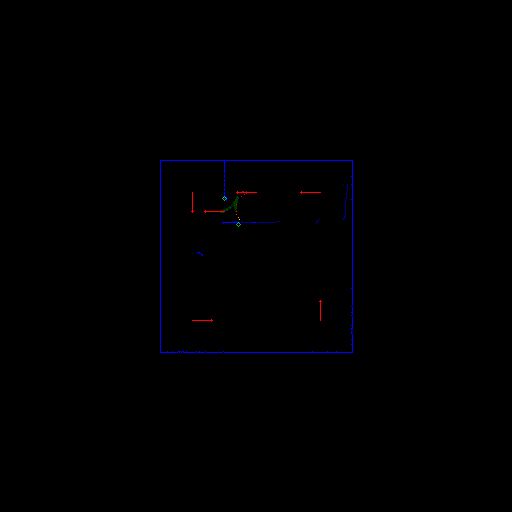
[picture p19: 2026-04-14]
code/raw_map.bmp

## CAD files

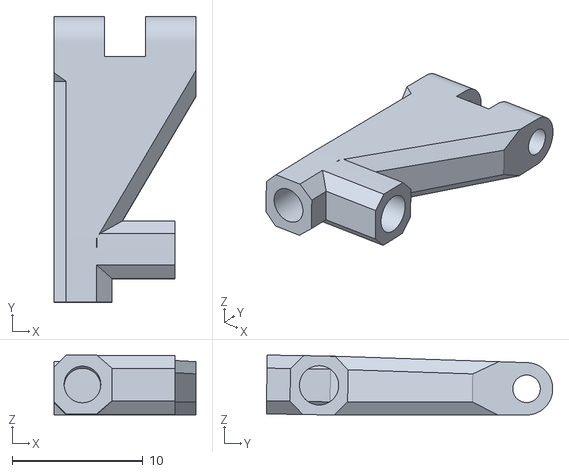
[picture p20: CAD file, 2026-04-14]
CAD Files/Confidence - Right Wishbone Bottom.stl
10.8 x 21.9 x 4.58

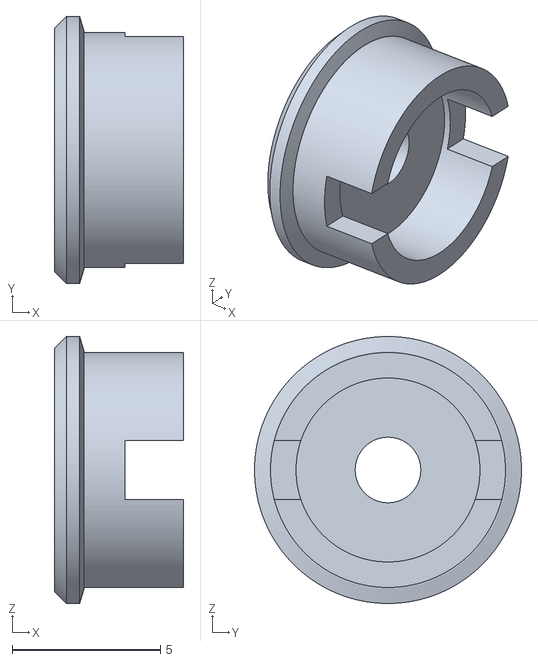
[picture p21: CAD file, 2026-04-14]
CAD Files/Confidence - Diff Bearing sleeve.stl
4.35 x 9.00 x 9.00

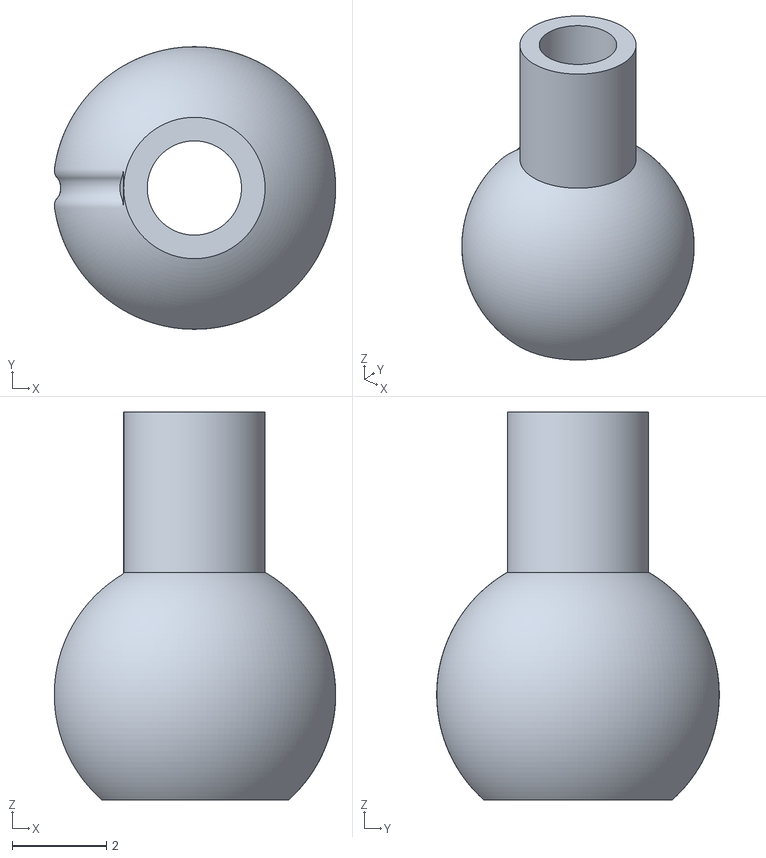
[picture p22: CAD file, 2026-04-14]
CAD Files/Confidence - Ball Joint.stl
5.97 x 6.00 x 8.24

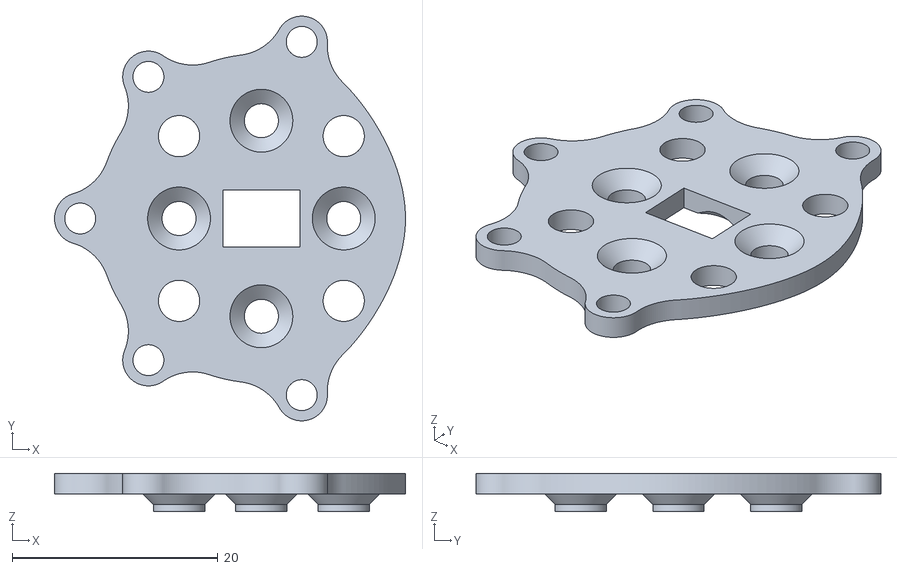
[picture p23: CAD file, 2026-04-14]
CAD Files/Confidence - Gearbox Motor Back Mount.stl
34.1 x 39.3 x 3.70

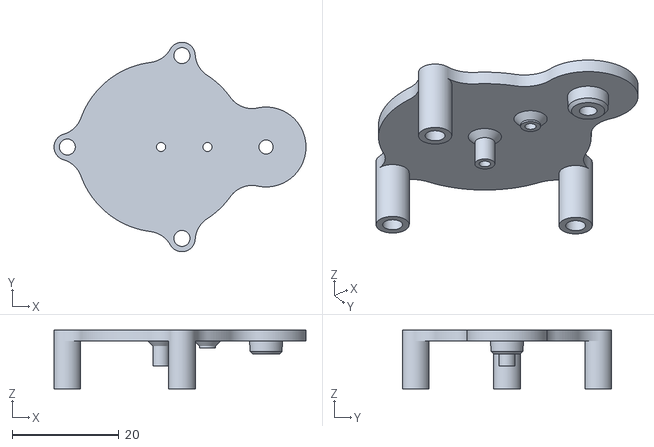
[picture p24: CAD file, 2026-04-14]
CAD Files/Confidence - Gearbox Motor Mount Front.stl
47.3 x 39.3 x 11.0

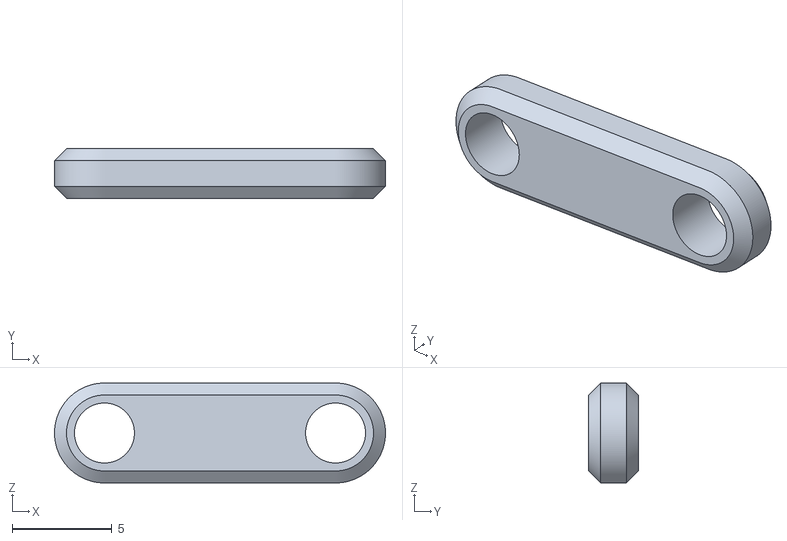
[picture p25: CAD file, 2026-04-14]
CAD Files/Confidence - Arm.stl
16.6 x 2.50 x 5.00

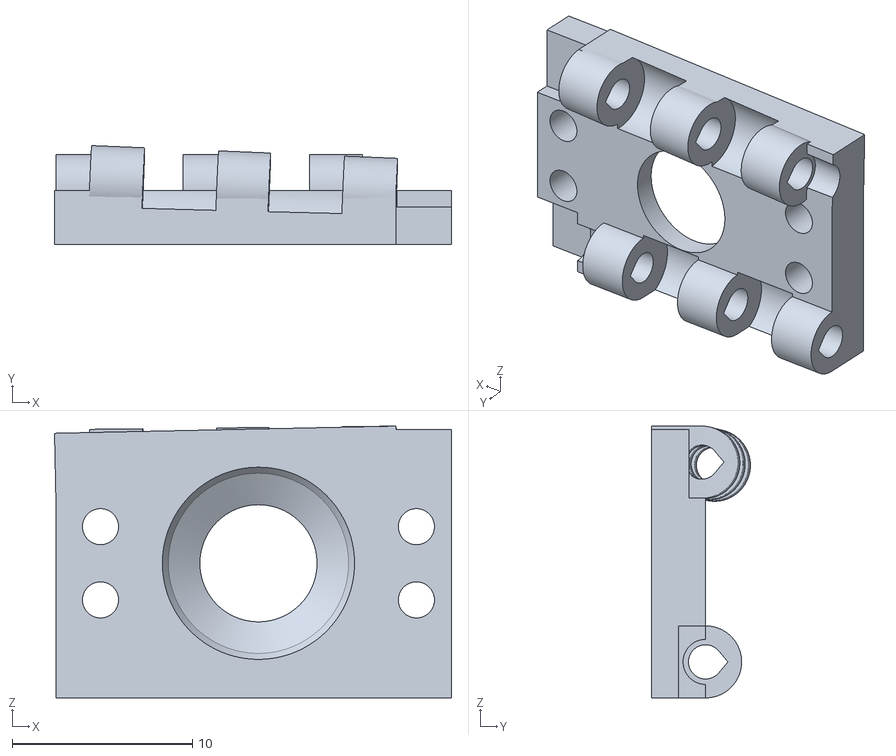
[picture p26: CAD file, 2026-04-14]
CAD Files/Confidence - Right Hinge Joint Back.stl
22.0 x 5.49 x 15.1

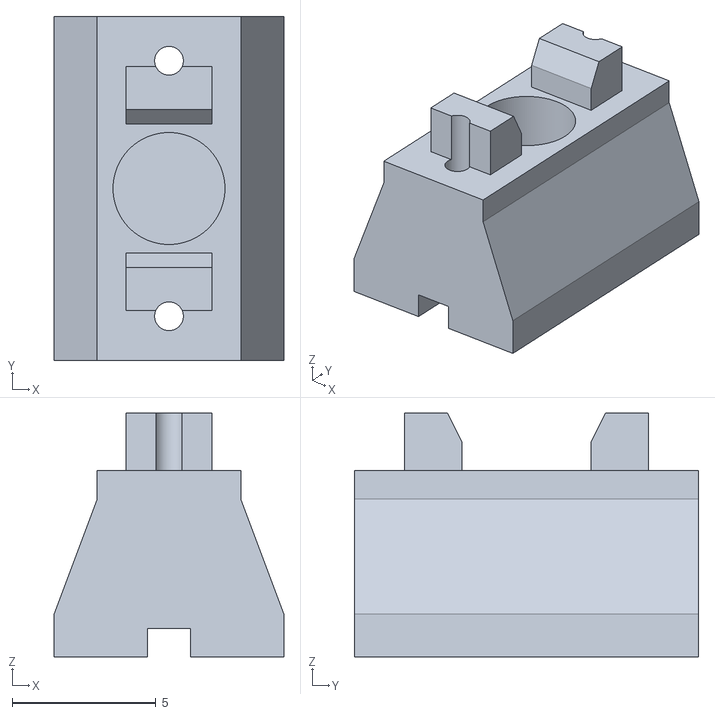
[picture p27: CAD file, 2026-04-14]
CAD Files/Confidence - String Mounting.stl
8.00 x 12.0 x 8.50

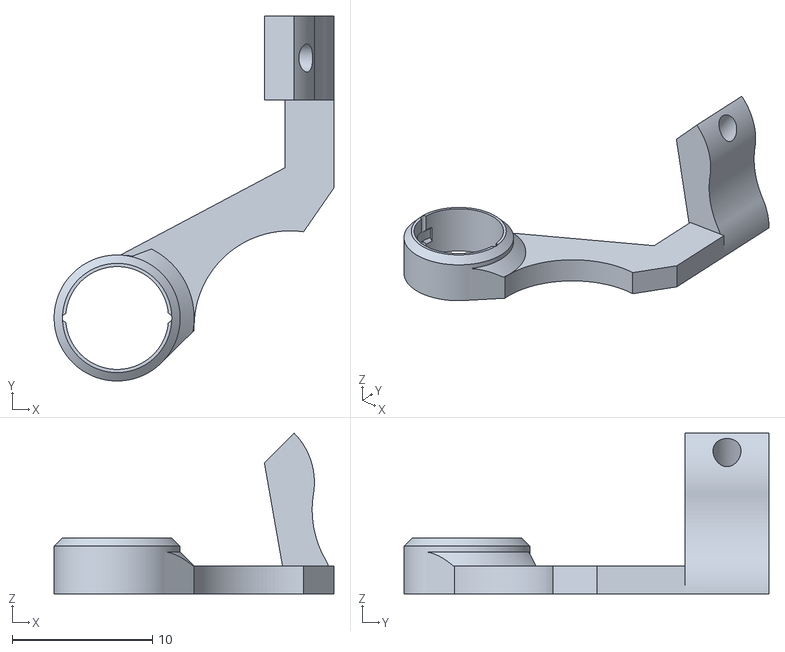
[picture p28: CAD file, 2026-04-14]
CAD Files/Confidence - Left Arm.stl
20.0 x 26.1 x 11.5

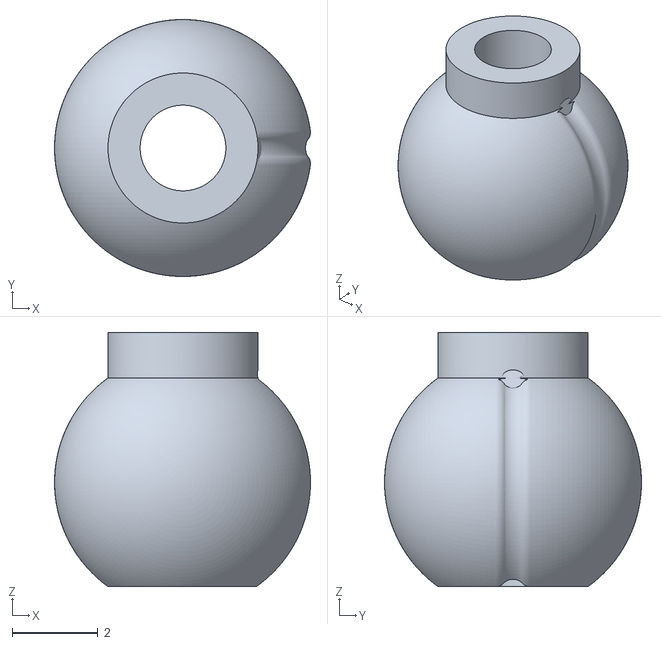
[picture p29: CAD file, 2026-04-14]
CAD Files/Confidence - Ball Joint A.stl
5.98 x 6.00 x 5.94

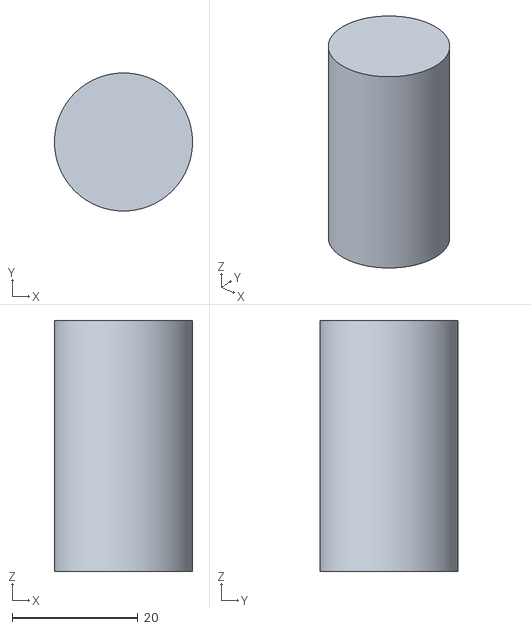
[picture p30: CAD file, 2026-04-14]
CAD Files/Confidence - Tire Cutting Tool.stl
22.0 x 22.0 x 40.0

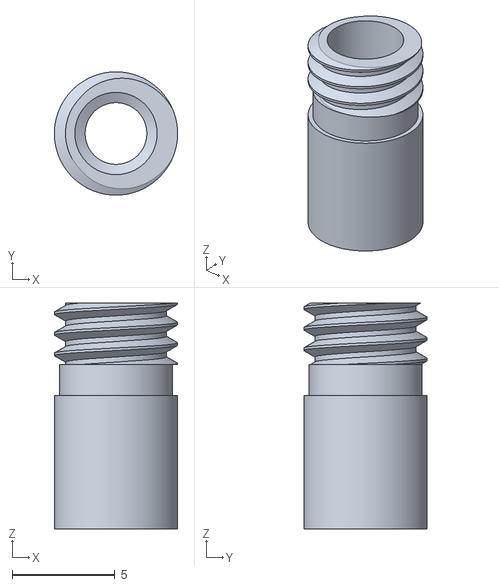
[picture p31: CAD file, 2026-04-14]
CAD Files/Confidence - Suspention Casing.stl
6.00 x 6.00 x 11.0

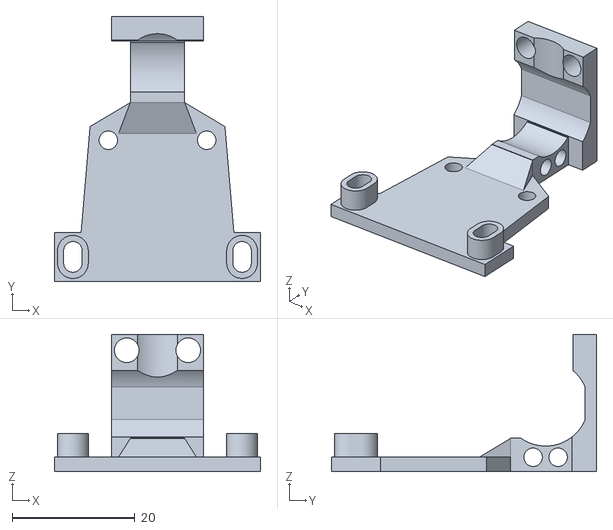
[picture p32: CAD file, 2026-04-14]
CAD Files/Confidence - Motor Mounting.stl
33.5 x 43.1 x 22.3

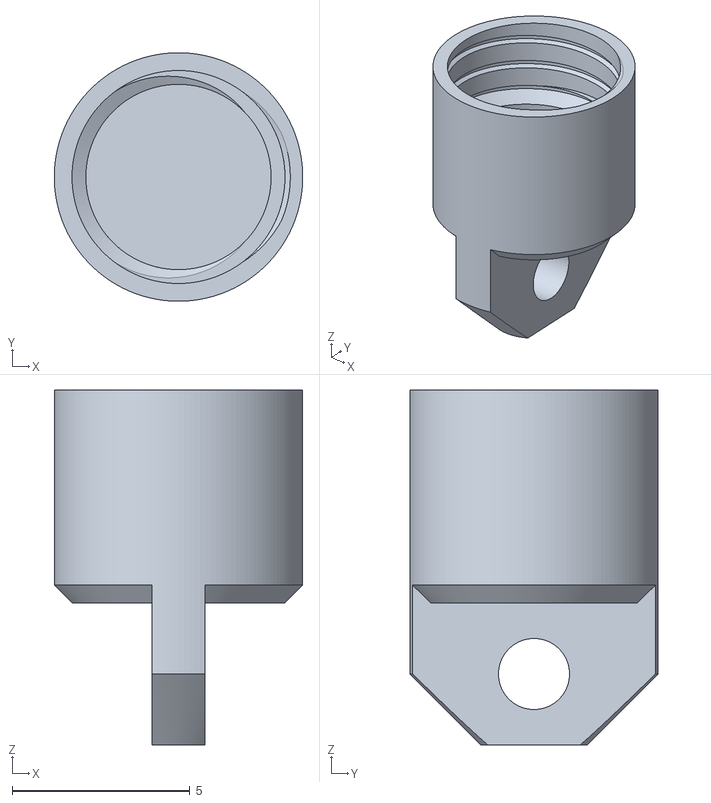
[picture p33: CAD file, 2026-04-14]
CAD Files/Confidence - Suspention Bottom.stl
7.00 x 7.00 x 10.0

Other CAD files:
CAD Files/Confidence - Left Wishbone Bottom.stl
CAD Files/Confidence - Right Hinge Joint.stl
CAD Files/Confidence - Suspention Top.stl
CAD Files/Confidence - Lidar Mounting.stl
CAD Files/Confidence - Ball Joint B.stl
CAD Files/Confidence - Differential Casing A.stl
CAD Files/Confidence - Differential Casing B.stl
CAD Files/Confidence - Flexible Cupling B.stl
CAD Files/Confidence - Flexsible Cupling A.stl
CAD Files/Confidence - Gearbox Motor Mount Middle.stl
CAD Files/Confidence - Left Arm Back.stl
CAD Files/Confidence - Left Body.stl
CAD Files/Confidence - Left Bottom Ball Joint Socket.stl
CAD Files/Confidence - Left Hinge Joint Back.stl
CAD Files/Confidence - Left Hinge Joint.stl
CAD Files/Confidence - Left Upper Ball Joint Socket.stl
CAD Files/Confidence - Left Wishbone Upper.stl
CAD Files/Confidence - Middle Arm.stl
CAD Files/Confidence - Right Arm Back.stl
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

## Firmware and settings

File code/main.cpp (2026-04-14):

#include "Config.h"
#include <iostream>
#include "stl27_driver.h"
#include "bno055_driver.h"
#include "icp.h"
#include "vison.h"
#include "drive.h"
#include "thread"
#include "pid.h"
#include "lookup.h"
#include "pathfinding.h"
#include "consts.h"
#include "signal.h"
#include "utils.h"


cv::Mat img = cv::Mat(512, 512, CV_8UC3, cv::Scalar(0,0,0,0));
void Display(std::vector<Point> reference){
    img -= cv::Scalar(150, 50, 1);
    int zoom = 64;
    for (Point& p: reference) {
        
        img.at<uchar>(std::clamp((int)(p.y * zoom + 256), 0, 511), std::clamp((int)(p.x * zoom + 256), 0, 511), 0) = 255;
        //cv::circle(img, cv::Point((int)(p.x * 256 + 256), (int)(p.y * 256 + 256)), 1, cv::Scalar(255,255,255));
        //img(cv::Rect(std::clamp((int)(p.x * zoom + 256), 0, 511), std::clamp((int)(p.y * zoom + 256), 0, 511), 1, 1)) = cv::Scalar(255, 0, 0);
        //img.at<uchar>(std::clamp((int)(p.x * zoom + 256), 0, 511), std::clamp((int)(p.y * zoom + 256), 0, 511)) = 255;
    }
    cv::imshow("cmb",img);
    return;
}

    std::vector<Point> reference;
    std::vector<std::vector<Point>> old_scans;
    double position_start[3] = {0, 0, 0};
    float target[3] = {};


    float last_click[2];
    float click_index = 0;
    bool has_target = false;
    void mouse_callback(int  event, int  x, int  y, int  flag, void *param)
    {
        if (event == cv::EVENT_LBUTTONDOWN ) {
            float x_cord = ((float) x - 256) / 64;
            float y_cord = ((float) y - 256) / 64;
            
            //HybridAStar pathfinder = HybridAStar(0.3, 0.2, Node(x_cord, y_cord, position_start[2] + PI / 2), Node(position_start[0], position_start[1], position_start[2] + PI / 2 ));
            //pathfinder.SetEnviorment(&reference);
            //std::vector<Node> pth;
            //int num = pathfinder.CalculatePath(&pth);
            
            if (click_index++ == 1) {
                target[0] = last_click[0];
                target[1] = last_click[1];
                target[2] = -atan2(last_click[1] - y_cord, -last_click[0] + x_cord);
                click_index = 0;
                cv::arrowedLine(img, cv::Point(last_click[0] * 64 + 256, last_click[1] * 64 + 256), cv::Point(last_click[0] * 64 + 256 + cos(target[2]) * 100, last_click[1] * 64 + 256 + sin(target[2]) * 100) , cv::Scalar(0, 0, 255));
                has_target = true;
            }
            last_click[0] = x_cord;
            last_click[1] = y_cord;

        }
    }

    void AddLine(std::vector<Point>* in, float x0, float y0, float x1, float y1, float density) {
        float len = sqrt((x0 - x1) * (x0 - x1) + (y0 - y1) * (y0 - y1));
        len *= density;

        for (int i = 0; i < len; i++) {
            float k = (float)i/len;
            in->push_back(Point(x0 * k + x1 * ( 1 - k), y0 * k + y1 * ( 1 - k)));
        }
    }

    


    int main() {
        std::cout << "Mode: Obsticle challenge\n";
        std::cout << "Initilizing robot sensors\n";

        Stl27_lidar lidar("/dev/ttyUSB0");
        lidar.FirstReading(1000); //Wait for first reading
        
        Bno055 imu("/dev/ttyS0");
        
        PointPair::quad_tree_opencl->CompileKernel();

        DriveBase car("/dev/ttyACM0");
        car.BindImu(&imu);


        while (true) {
            bool condition = true;
            for (int i = 0; i < 2; i++) {
                condition &= car.IsButtonPressed();
                std::this_thread::sleep_for(std::chrono::milliseconds(100));
            }
            if (condition) {
                break;
            }
        }

        car.SetLedPWM(5);
        std::this_thread::sleep_for(std::chrono::milliseconds(100));
        

        #ifdef OBSTACLE_CHALLENGE
        Vision vis;
        vis.AddLidar(&lidar);
        vis.AddImu(&imu);
        #endif

        

        cv::Mat allowed_point_mask = cv::imread("obsticle_challenge_mask.bmp", cv::ImreadModes::IMREAD_GRAYSCALE);

        #ifdef DEBUG_DISPLAY
        cv::namedWindow("cmb");
        cv::setMouseCallback("cmb", mouse_callback);
        cv::namedWindow("cmb");
        cv::moveWindow("cmb", 600, 0);
        #endif

        std::this_thread::sleep_for(std::chrono::milliseconds(100));
        
        
        AddLine(&reference, -1.5, -1.5, 1.5, -1.5, 100);
        AddLine(&reference, 1.5, -1.5, 1.5, 1.5, 100);
        AddLine(&reference, 1.5, 1.5, -1.5, 1.5, 100);
        AddLine(&reference, -1.5, 1.5, -1.5, -1.5, 100);
        #ifdef OBSTACLE_CHALLENGE
        AddLine(&reference, -0.5, -1.5, -0.5, -1.3, 100);
        AddLine(&reference, -0.25, -1.5, -0.25, -1.3, 100);
        #endif

        std::this_thread::sleep_for(std::chrono::seconds(1));
        
        std::vector<Point> compare_start;
        lidar.GetBilateralFiltered(&compare_start, imu, true);
        #ifdef OBSTACLE_CHALLENGE
        std::vector<std::vector<float>> possible_positions = {
            {-0.25, -1.0, PI/2},
            {-0.25, -1.0, -PI/2},
        };
        #endif
        #ifdef OPEN_CHALLAGE 
        std::vector<std::vector<float>> possible_positions = {
            {-0.25, -0.7, -PI/2},
            {-0.25, -1.0, -PI/2},
            {-0.25, -1.3, -PI/2},
            {+0.25, -0.7, -PI/2},
            {+0.25, -1.0, -PI/2},
            {+0.25, -1.3, -PI/2},
            {-0.25, -0.7, +PI/2},
            {-0.25, -1.0, +PI/2},
            {-0.25, -1.3, +PI/2},
            {+0.25, -0.7, +PI/2},
            {+0.25, -1.0, +PI/2},
            {+0.25, -1.3, +PI/2},
        };
        #endif
        
        std::vector<float> best_position = BestPosition(possible_positions, reference, compare_start);

        #ifdef DO_PARK_END
            Waypoint::final_waypoint = Waypoint(-0.3725, -1.4, best_position[2] + PI/2, true);
        #else
            Waypoint::final_waypoint = Waypoint(best_position[0], best_position[1], best_position[2] + PI/2, true);
        #endif
        
        Signal::Direction direction = Signal::Direction::CW;
        
        position_start[0] = best_position[0];
        position_start[1] = best_position[1];
        position_start[2] = best_position[2];

        if (best_position[2] > 0) {    
            direction = Signal::Direction::CCW;
        }
        
        #ifdef OBSTACLE_CHALLENGE
        Waypoint(1, -1, PI / 2 + (direction == Signal::Direction::CW ? 0 : PI/2), 500);
        Waypoint(1, 1, PI + (direction == Signal::Direction::CW ? 0 : PI/2), 500);
        Waypoint(-1, -1, (direction == Signal::Direction::CW ? 0 : PI/2), 500);
        Waypoint(-1, 1, 3 * PI / 2 + (direction == Signal::Direction::CW ? 0 : PI/2), 500);
        #endif
        #ifdef OPEN_CHALLENGE
        Waypoint(1.2, -1.2, PI / 2 + (direction == Signal::Direction::CW ? -PI/4 : 3*PI/4));
        Waypoint(1.2, 1.2, PI + (direction == Signal::Direction::CW ? -PI/4 : 3*PI/4));
        Waypoint(-1.2, -1.2, (direction == Signal::Direction::CW ? -PI/4 : 3*PI/4));
        Waypoint(-1.2, 1.2, 3 * PI / 2 + (direction == Signal::Direction::CW ? -PI/4 : 3*PI/4));
        #endif

        
        float imu_offset = imu.GetHeading() - position_start[2];
        car.SetHeadingOffset(imu_offset);
        #ifdef DEBUG_INPUT
        bool auto_skip = false;
        #else 
        bool auto_skip = true;
        #endif
        
        auto last_pathfind = std::chrono::high_resolution_clock::now();
        auto waypoint_time = std::chrono::high_resolution_clock::now();
        auto imu_recalibration_timeout = std::chrono::high_resolution_clock::now();
        int waypoint_timeout = 0; 

        while(true) {

            std::vector<Point> compare;
            lidar.GetBilateralFiltered(&compare, imu, true);
            
            auto start_time = std::chrono::high_resolution_clock::now();
            
            position_start[2] = AngleMod(position_start[2]);
            Point delta_drive = car.GetDelta(-position_start[2] - PI/2);
            position_start[0] += delta_drive.x;
            position_start[1] -= delta_drive.y;
            position_start[2] = imu.GetHeading() - imu_offset;
            for (Point &p :compare) {
                p.Transform(position_start[0], position_start[1], position_start[2]);
            }


            ICP icp;
            float dx = 0;
            float dy = 0;
            float da = 0;
            double cost;
            int iterations = icp.Compute(compare, reference, dx, dy, da, cost, false);
            
            #ifdef DEBUG_DISPLAY
            Display(compare);
            #endif

            if (!isnanf(dx) && !isnanf(dy) && !isnanf(da) && abs(dx) < 0.25 && abs(dy) < 0.25 && abs(da) < 0.32 && cost < 0.5) {
                Point total = Point(0, 0);
                total.Transform(position_start[0], position_start[1], position_start[2]);
                total.Transform(dx, dy, da);
                
                position_start[0] = total.x;
                position_start[1] = total.y;
                position_start[2] = da + position_start[2];
                icp.MergeMaps(reference, old_scans, 4, allowed_point_mask);
                old_scans.push_back(compare);
            
                if (cost < 0.025 && std::chrono::duration_cast<std::chrono::milliseconds>(std::chrono::high_resolution_clock::now() - imu_recalibration_timeout).count() < 1000) {
                    position_start[2] = AngleMod(position_start[2]);
                    imu_offset = imu.GetHeading() - position_start[2];
                    car.SetHeadingOffset(imu_offset);
                }
            }

            #ifdef OBSTACLE_CHALLENGE
            std::vector<Signal> signals = vis.DisplayFrame();
            for (Signal& s : signals) {
                s.Transform(position_start[0], position_start[1], position_start[2]);
                if (abs(s.x) < 1.4 && abs(s.y) < 1.4) {
                    cv::circle(img, cv::Point(s.x * 64 + 256, s.y * 64 + 256), 0.03535 * 64, s.color == Signal::Color::RED ? cv::Scalar(0, 0, 255, 255) : cv::Scalar(0, 255, 0, 255));
                }
                
            }
            Signal::MergeSignals(signals, direction);
            #endif
            
            std::vector<Point> reference_copy = reference;
            #ifdef OBSTACLE_CHALLENGE
            for (Signal& s : Signal::total_signals) {
                if (abs(s.x) < 1.4 && abs(s.y) < 1.4) {
                    cv::circle(img, cv::Point(s.x * 64 + 256, s.y * 64 + 256), 0.03535 * 64, s.color == Signal::Color::RED ? cv::Scalar(0, 0, 255, 255) : cv::Scalar(0, 255, 0, 255));
                }
                s.AddVirtualWall(&reference_copy);
                s.AddWaypoint();
            }
            #endif

            for (Waypoint& w : Waypoint::waypoints) {
                cv::arrowedLine(img, cv::Point(w.x * 64 + 256, w.y * 64 + 256), cv::Point(w.x * 64 + 256 + cos(w.a) * 20, w.y * 64 + 256 + sin(w.a) * 20) , cv::Scalar(0, 0, 255));
            }
            
            #ifdef DEBUG_DISPLAY
            Display(reference_copy);
            #endif

            Node car_pos = Node(position_start[0] + sin(position_start[2]) * 0.065, position_start[1] - cos(position_start[2]) * 0.065, position_start[2] + PI/2);
            car.UpdatePosition(car_pos.x, car_pos.y, car_pos.a);

            if (has_target && std::chrono::duration_cast<std::chrono::milliseconds>(std::chrono::high_resolution_clock::now() - last_pathfind).count() > 100) {
                last_pathfind = std::chrono::high_resolution_clock::now();

                HybridAStar pathfinder = HybridAStar(0.35, 0.08, Node(target[0], target[1], target[2]), car_pos);
                pathfinder.SetEnviorment(&reference_copy);
                std::vector<Node::NodeReedSheps> pth;
                Node::NodeReedSheps current_drive_node = car.GetCurrentNode();
                int num = pathfinder.CalculatePath(&pth, current_drive_node);
            
                if (num < 0) {
                    has_target = false;
                }
                else {
                car_pos.pathfinder = &pathfinder;
                std::vector<Node> vis_path = Subdevide(pth, &car_pos);

                for (int i = 0; i < vis_path.size(); i++) {
                    cv::circle(img, cv::Point((int)(vis_path[i].x * 64 + 256), (int)(vis_path[i].y * 64 + 256)), 1, cv::Scalar(0,255,0));
                }

                car.DrivePath(pth, 5000, car_pos.x, car_pos.y, car_pos.a);
                }
            }
            
            if (sqrt((target[0] - car_pos.x) * (target[0] - car_pos.x) + (target[1] - car_pos.y) * (target[1] - car_pos.y)) < 0.2 && abs(AngleMod(target[2] - car_pos.a)) < 0.2  && has_target) {
                has_target = false;
                waypoint_time = std::chrono::high_resolution_clock::now();
                std::vector<Node::NodeReedSheps> pth_temp;
                car.DrivePath(pth_temp, 10, car_pos.x, car_pos.y, car_pos.a);
            }

            img(cv::Rect(std::clamp((int)(position_start[0] * 64 + 256), 0, 511), std::clamp((int)(position_start[1] * 64 + 256), 0, 511), 1, 1)) = cv::Scalar(0, 255, 255);
            
            auto end = std::chrono::high_resolution_clock::now();
            std::cout << "loop took: " << std::chrono::duration_cast<std::chrono::milliseconds>(end - start_time).count() << "ms \t";
            std::cout << "dr delta: " << delta_drive.x << ", " << delta_drive.y << ", " << car.EncoderAngle() << "\t";
            std::cout << std::fixed << std::setprecision(3) << position_start[0] << ", " << position_start[1] << ", " << position_start[2]  << ", imu:" << imu.GetHeading() - imu_offset << ", " << cost * 1000 << ", " << iterations << "\n";
            
            #ifdef DEBUG_INPUT
            int id = cv::waitKey(1);

            if (id == 97) {
                std::vector<Node::NodeReedSheps> pth_temp;
                car.DrivePath(pth_temp, 10, car_pos.x, car_pos.y, car_pos.a);
                car.SendCommand(0,0);
                std::this_thread::sleep_for(std::chrono::milliseconds(1000));
                car.SetLedPWM(50);
                return 0;
            }
            else if (id == 83) {
                auto_skip = !auto_skip;
            }
            else if (id == 115) {
                cv::imwrite("raw_map.bmp", img);
            }
            #endif

            if (auto_skip && !has_target && std::chrono::duration_cast<std::chrono::milliseconds>(std::chrono::high_resolution_clock::now() - waypoint_time).count() > waypoint_timeout) {
                std::cout << "\n NEXT WAYPOINT CALLED \n\n";

                if (Waypoint::reached_final) {
                    std::vector<Node::NodeReedSheps> pth_temp;
                    car.DrivePath(pth_temp, 10, car_pos.x, car_pos.y, car_pos.a);
                    car.SendCommand(0,0);
                    std::this_thread::sleep_for(std::chrono::milliseconds(1000));
                    car.SetLedPWM(50);
                    return 0;
                }
                
                Waypoint w = Waypoint::GetNextWeypoint(position_start[0], position_start[1], (bool)direction);
                target[0] = w.x;
                target[1] = w.y;
                target[2] = w.a;
                has_target = true;
                waypoint_timeout = w.wait;          
            }

        }
    }

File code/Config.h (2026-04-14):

#pragma once



#define OBSTACLE_CHALLENGE
#define DO_PARK_END

//#define OPEN_CHALLENGE


#define NUMBER_OF_TURNS 3

#define DEBUG_DISPLAY
#define DEBUG_INPUT

#define DOMAIN_SIZE -4, -4, 8
#define DELAY_AFTER_READ_BNO 6
#define DELAY_AFTER_READ_RP2040 5

#define POINT_MATCHING_QUAD_TREE_OPENCL

#define ALGORITHM_ICP

#define MIN_ITERATIONS 1
#define MAX_ITERATIONS 100
#define CONVERGANCE_CONDITION 0.00000000015
#define COST_CONDITION 0.00005


#define BUFFER_SIZE 262144
#define CL_TARGET_OPENCL_VERSION 300

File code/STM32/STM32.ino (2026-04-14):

#include <Wire.h>
#include <SCServo.h>
#include <HardwareTimer.h>

SMS_STS st;
#define button PB10
#define LED_CHANNEL 1

HardwareSerial Serial2(PA3, PA2);
HardwareTimer *timer2 = new HardwareTimer(TIM4);
HardwareTimer *timerled = new HardwareTimer(TIM2);


void setup() {
  Serial1.setTx(PA9);
  Serial1.enableHalfDuplexRx();
  Serial1.setHalfDuplex();
  Serial1.begin(1000000);
  st.pSerial = &Serial1;  

  Wire.setSCL(PB6);
  Wire.setSDA(PB7);
  Wire.setClock(400000);
  Wire.begin();
  
  Serial2.begin(57600);
  
  
  pinMode(button, INPUT_PULLDOWN);

  HardwareTimer *timer1 = new HardwareTimer(TIM1);
  timer1->setOverflow(1400, HERTZ_FORMAT);
  timer1->attachInterrupt(UpdateEncoder);
  timer1->resume();

  timer2->setMode(4, TIMER_OUTPUT_COMPARE_PWM1, PB9);
  timer2->setPrescaleFactor(8);
  timer2->setOverflow(20000, MICROSEC_FORMAT);
  timer2->setCaptureCompare(4, 1500, MICROSEC_COMPARE_FORMAT);
  timer2->refresh();
  timer2->resume();

  timerled->setMode(LED_CHANNEL, TIMER_OUTPUT_COMPARE_PWM1, PA15);
  timerled->setPrescaleFactor(100 * 50);
  timerled->setOverflow(20000, TICK_FORMAT);
  timerled->setCaptureCompare(LED_CHANNEL, 10000, TICK_COMPARE_FORMAT);
  timerled->refresh();
  timerled->resume();
}

int angle = 0;
int accumulation = 0;
int last_angle = 0;

void UpdateEncoder() {

  Wire.beginTransmission(0x36);
  Wire.write(0x0C);
  Wire.endTransmission();
  Wire.requestFrom(0x36, 2);
  int new_angle = 0;
  if (2 <= Wire.available()) {
    new_angle = Wire.read() & 0x0F;
    new_angle = new_angle << 8;
    new_angle |= Wire.read();
  }

  if (abs(new_angle - last_angle) > 3000) {
    if (new_angle > last_angle) {
      accumulation -= 4096;
    } else {
      accumulation += 4096;
    }
  }
  last_angle = new_angle;
  angle = accumulation + new_angle;
}

int num = 0;

int wait_for_packet(uint8_t *data) {
  while (true) {
    if (Serial2.available()) {
      uint8_t byte = Serial2.read();

      for (int i = 0; i < 2; i++) {
        if (byte == 0x35 && num == 0) {
          num++;
          break;
        }
        else if (byte == 0x80 && num == 1) {
          num++;
          break;
        }
        else if (num == 2) {
          data[0] = byte;
          num++;
          break;
        }
        else if (num == 3) {  
          data[1] = byte;
          num++;
          break;
        }
        else if (num == 4) {
          
          data[2] = byte;
          uint8_t response[7];
          response[0] = 0x35;
          response[1] = 0x01;
          memcpy(response + 2, &angle, sizeof(int));
          response[6] = digitalRead(button) ? 255 : 0; 
          Serial2.write(response, 7);
          num = 0;
          return 0x80;  
        
        }
        else {
          num = 0;
        }
      }
    }
  }
}

void loop() {
  
  uint8_t data[3] = { 127, 127, 127};
  int cmd = wait_for_packet(data);
  if (cmd == 0x80) {
    int steer_pos = 1400 + data[1] * (2600 - 1400) / 256;
    steer_pos = std::clamp(steer_pos, 1300, 2700);
    st.WritePosEx(1, steer_pos, 4096, 250);

    int drive_speed = 1060 + (1860 - 1060) * data[0] / 256;
    drive_speed = std::clamp(drive_speed, 1060, 1860);
    timer2->setCaptureCompare(4, drive_speed, MICROSEC_COMPARE_FORMAT);
    timerled->setPrescaleFactor(100 * data[2]);
    timerled->refresh();
    timerled->resume();
  }

}

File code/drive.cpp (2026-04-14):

#include "drive.h"
#include <termios.h>
#include <fcntl.h>
#include <unistd.h>
#include <iostream>
#include <chrono>
#include <cstring>
#include "Config.h"
#include <algorithm>
#include "lookup.h"
#include "pid.h"
#include "consts.h"

DriveBase::DriveBase(const char* port) {
    
    std::cout << "\n===============================================\n";
    std::cout << "Initilizing DriveBase communication on port: " << port << "\n";

    serial_port = open(port, O_RDWR);
    if (serial_port == -1) {
        std::cout << "\nERROR: Unable to open port: " << port << " with errno: " << errno << " \n";
        return;
    }

    std::cout << "Configuring serial port: \n";
    
    termios config;
    tcgetattr(serial_port, &config);
    cfmakeraw(&config);
    cfsetispeed(&config, B115200);
    cfsetospeed(&config, B115200);
    std::cout << "\tBaudrate: 115200\n";

    config.c_cc[VMIN]  = 0;
    config.c_cc[VTIME] = 0;
    std::cout << "\tTimeout: 0\n";

    config.c_cflag |= (tcflag_t)(CLOCAL | CREAD | CS8);
    config.c_cflag &= (tcflag_t) ~(CSTOPB | PARENB);
    config.c_lflag &= (tcflag_t) ~(ICANON | ECHO | ECHOE | ECHOK | ECHONL |
                                   ISIG | IEXTEN);
    config.c_oflag &= (tcflag_t) ~(OPOST);
    config.c_iflag &= (tcflag_t) ~(IXON | IXOFF | INLCR | IGNCR | ICRNL | IGNBRK);
    std::cout << "\tc_cflag configured\n";
    std::cout << "\tc_lflag configured\n";
    std::cout << "\tc_iflag configured\n";
    std::cout << "\tc_oflag configured\n";
    
    tcsetattr(serial_port, TCSANOW, &config);
    std::cout << "Apllying config\n";

    tcflush(serial_port, TCIFLUSH);
    std::cout << "Flusing old data\n";

    comms = std::thread(&DriveBase::CommandLoop, this);
    process = std::thread(&DriveBase::PathLoop, this);
    std::cout << "Starting path loop on thread: " << process.get_id() << "\n";

    std::cout << "===============================================\n\n";
}

DriveBase::~DriveBase(){
    std::cout << "Stopping car\n";
    SendCommand(0,0);
    std::cout << "Closing RP2040 serial port\n";
    close(serial_port);
}

void DriveBase::Write(uint8_t cmd, uint8_t* data, int len) {
    uint8_t* buf = (uint8_t*)malloc((2 + len) * sizeof(uint8_t));
    buf[0] = 0x35;
    buf[1] = cmd;
    memcpy(buf + 2, data, len);
    int err = write(serial_port, buf, 2 + len);
    if (err < 0) {
        std::cout << "\tError writing to RP2040 port\n";
    }
    free(buf);
}

DriveBase::Response DriveBase::Read(int timeout) {
    auto start = std::chrono::high_resolution_clock::now();
    uint8_t data[7] = {};
    int i = 0;
    while (i < 7){
        if (std::chrono::duration_cast<std::chrono::milliseconds>(std::chrono::high_resolution_clock::now() - start).count() > timeout) {
            //data[0] = 0;
            break;
        }

        int ret = read(serial_port, data + i, 1);
        if (ret <= 0) {
            std::this_thread::sleep_for(std::chrono::microseconds(100));
            continue;
        }
        if (i == 0 && data[0] != 0x35) {
            continue;
        }
        i += ret;
    }

    DriveBase::Response response = {};
    if (i < 7) {
        response;
    }

    response.header = data[0];
    response.ack = data[1];
    memcpy(&(response.data), data + 2, 4);        

    this->button = data[6];

    std::this_thread::sleep_for(std::chrono::milliseconds(DELAY_AFTER_READ_RP2040));
    return response;
}

bool DriveBase::SendCommand(float drive_set, float turn_set) {
    drive_set /= 2;
    if (drive_set > 0) {
        drive_set /= 0.97;
        drive_set += 0.22;
    }
    else {
        drive_set /= 1.22;
    }

    drive_set = std::clamp(drive_set, -0.4f, 0.62f);
    //drive_set += 0.1f * (drive_set >= 0 ? 1 : -1);
    turn_set = std::clamp(turn_set, -1.f, 1.f);
    comms_mutex.lock();

    this->turn = turn_set;
    this->drive = drive_set;

    comms_mutex.unlock();

    return true;
}

void DriveBase::DrivePath(std::vector<Node::NodeReedSheps>& path, int max_drive_time, float x, float y , float a) {
    

    this->writing_mutex.lock();
    this->new_command = true;
    this->x = x;
    this->path_x = x;
    this->y = y;
    this->path_y = y;
    this->a = a;
    this->path_a = a;
    this->current_path = path;
    this->max_drive_time = max_drive_time;

    this->writing_mutex.unlock();
}

Node::NodeReedSheps DriveBase::GetCurrentNode() {
    writing_mutex.lock();
    Node::NodeReedSheps current_node = current_step;
    current_node.distance -= current_distance;
    writing_mutex.unlock();
    return current_node;
}

void DriveBase::CalculateClosestPoint(std::vector<Node::NodeReedSheps> &path, float& d_min, float& a_min, float& point_x, float &point_y, float k, float &till_end, float delta_x, float delta_y, float delta_a) {
    
    float min_distance = 10000000;
    
    int j = 0;
    float xp = this->path_x;
    float yp = this->path_y;
    float ap = this->path_a;
    float look_ahead = 100000;
    for (Node::NodeReedSheps& n : path) {
        float t = 0;
        while (true) {
            float min_d = std::min(n.distance - t, 0.02f);

            if (n.steering != 0) {
                xp += (sin(a) - sin(a - min_d/this->min_radius * n.steering * n.drive)) * this->min_radius * n.steering;
                yp -= (cos(a) - cos(a - min_d/this->min_radius * n.steering * n.drive)) * this->min_radius * n.steering;
                ap -= min_d/this->min_radius * n.steering * n.drive;
            }
            else {
                xp += cos(a) * min_d * n.drive;
                yp += sin(a) * min_d * n.drive;
            }
            t += min_d;
            float distance = pow(xp - this->x - delta_x - delta_y, 2) + pow(yp - this->y, 2);
            if (distance < min_distance) {
                min_distance = distance;
                a_min = ap;
                point_x = xp;
                point_y = yp;
                d_min = sqrt(distance);
                look_ahead = 0;
            }

            if (look_ahead < k) {
                a_min = ap;
                point_x = xp;
                point_y = yp;
                till_end = 0;
            }
            till_end += min_d;
            look_ahead += min_d;

            if (abs(t - n.distance) < 0.00001) {
                break;
            }
        }
        j++;
    }

}
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
